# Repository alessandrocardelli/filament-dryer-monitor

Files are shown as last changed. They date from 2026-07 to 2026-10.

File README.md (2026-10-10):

# Filament Dryer Monitor

Custom ESP32-based controller board that retrofits an **eSUN eBox** filament dryer with closed-loop humidity/temperature control, a local OLED interface, data logging and a web UI.

The PCB physically replaces the original front panel: display and buttons sit on the front face of the board, while the main electronics are on the back.

> **Current status — 2026-10-08:** active hardware branch **main**. The released fabrication-source checkpoint remains **`74a3000127371ac6c3b3b7197f9036dec5b58eef`** (2026-09-17). First-article bring-up has validated MCU/USB/UART after the documented D020 collector-cross bodge, the four front-panel buttons, internal diagnostic LED, passive buzzer, SHT45, SSD1309 graphical output, fan driver/real fan and unloaded heater-switching path. The real heater remains blocked pending the real NTC/J7 path, final NTC conversion/fault handling and independent series TCO. The V1 front-panel interaction model is specified in `docs/UI_SPEC.md` and D022. A **SAFE BRING-UP** application now exists under `firmware/`: Slewform animated root-growth startup followed by a separate wordmark/chime (reproducible SVG-to-XBM export), OLED pages, SHT45 acquisition, button handling, persisted settings, modular cycle/fan/safety controllers and D021 LED patterns are implemented. The heater remains hard-locked LOW; the already-validated fan is now enabled only during DRYING test cycles with a provisional 100%/1 s kick-start followed by 40% at 25 kHz. See `docs/PROJECT_STATE.md` and `hardware/docs/PROCUREMENT.md`.

For a new work session, read AGENTS.md, docs/PROJECT_STATE.md, docs/DECISIONS.md and docs/TODO.md before changing the design.

---

## Features

- **SHT45** humidity/temperature sensor (I²C)
- **Characterized NTC thermistor** integrated into the heating element
- **1.54 in SSD1309 OLED** (128×64, I²C) + four front-panel buttons
- PWM heater control with hardware and firmware safety layers
- PWM fan control
- CSV logging to internal flash planned
- Web UI planned
- Powered from the dryer's 24 V supply; USB is used for programming/debug

## Safety concept

The project keeps three independent safety layers for the heater:

1. **Hardware TCO** in series with HEATER+, off-board and independent of the MCU.
2. **Firmware safety loop** using the heater NTC; an invalid/open sensor is treated as a fault and disables the heater.
3. **Compile-time gate**: heater drive is disabled until NTC calibration is explicitly enabled.

This is a personal project and not a certified product.

---

## Hardware

The board is a 4-layer KiCad 10 design intended for JLCPCB **bare-board fabrication and manual component assembly**. TME is the preferred prototype component supplier. The current KiCad schematic and PCB on the active branch are the authoritative implementation.

### Main blocks

| Block | Part | Notes |
|---|---|---|
| MCU | ESP32-WROOM-32E | Wi-Fi; final antenna copper/edge review remains a release item |
| Buck converter | **L7987L** | 24V_PROT -> 3.3 V, about 516 kHz, 1 A design target |
| Buck fault recovery | TLV1701AIDBVR + MMBT3904 | External AutoEN based on COMP fault detection |
| USB-UART | CP2102-GM | USB Full-Speed programming/debug |
| USB ESD | AKS1201 / USBLC6-2SC6-compatible topology | Two protected data channels |
| Humidity/temp | SHT45 | I²C 0x44 |
| Display | SSD1309 OLED 128×64 | I²C 0x3C |
| Heater driver | IRLR3636TRPBF | 60 V DPAK N-MOSFET, about 1.6 A heater load |
| Fan driver | IRLML2060TRPBF | 24 V fan low-side switch |
| Heater temperature | Integrated ~82 kΩ NTC | GPIO34 / ADC1, R28 = 47 kΩ, C19 = 100 nF |
| Buzzer | Passive buzzer + NPN | Defined startup state with base-emitter pull-down |

Heater and fan stay on 24V_PROT; they are not powered by the 3.3 V buck.

### L7987L electrical state

The active implementation is in hardware/Power.kicad_sch.

Key implemented parts/values:

| Ref | Value / part | Role |
|---|---|---|
| U5 | L7987L | Buck regulator |
| U1 | TLV1701AIDBVR | AutoEN comparator |
| Q7 | MMBT3904 | AutoEN EN pull-down |
| L1 | SRN6045-150M, 15 µH | Inductor |
| D7 | PMEG6030EP,115 | Catch diode, 60 V / 3 A Schottky |
| C1 | 10 µF / 100 V X7S | Main local input ceramic |
| C3 | 1 µF / 100 V X7S | Current local VIN/VCC bypass present in source |
| C6 | 100 nF | BOOT-LX bootstrap |
| C10 | 47 µF / 10 V X7R | Main pre-bead output capacitor |
| C21 | 1 µF / 25 V | VBIAS bypass |
| R4 | 47 kΩ | FSW, ~516 kHz |
| R29 | 47.5 kΩ | ILIM, ~1.705 A nominal |
| R36 / R34 | 49.9 kΩ / 16 kΩ | Feedback, ~3.295 V nominal |

Compensation: R33 = 16 kΩ, C9 = 18 nF, C8 = 39 pF, R35 = 1.13 kΩ, C20 = 560 pF.

Output architecture remains 3V3_BUCK -> FB1 -> 3V3_MCU. PGOOD and SYNCH are intentionally NC. The upstream C5 = 100 µF / 50 V bulk capacitor remains.

**VIN/VCC ceramic bypass — resolved:** ST requires a ceramic of 1 µF or higher across VIN-to-power-GND and another across VCC-to-IC-GND, close to the device. In the current design C1 = 10 µF / 100 V X7S already satisfies the VIN-side requirement, while C3 = 1 µF / 100 V X7S is the VCC bypass. The extra buck C22 added on 2026-09-09 was therefore redundant and was deliberately removed in commit `24a9170a`. Current C22 is unrelated: it is the CP2102 REGIN 1 µF / 25 V capacitor.

Detailed calculations and AutoEN rationale are in [docs/BUCK_L7987L_DESIGN.md](docs/BUCK_L7987L_DESIGN.md).

### Engineering review

The L7987L + AutoEN engineering review completed on **2026-09-04**. The accepted design basis remains:

- R29 = 47.5 kΩ -> ~1.705 A nominal current limit;
- conservative component-selection envelope ~1.42–2.15 A;
- actual sourced C1/C10 reviewed with class-II MLCC bias sensitivity;
- AutoEN reviewed COMP trip window ~1.56–2.07 V;
- recorded simulation ~59.1 kHz crossover, 64.9° phase margin, 19.6 dB gain margin.

These are engineering/simulation results; physical validation remains required.

The current `hardware/ERC.rpt` (2026-09-17) reports **0 errors and 0 warnings**. The existing GitHub ERC workflow contains the reviewed waiver logic, but its automatic push trigger currently names redesign/buck-sourcing, not the active pcb/l7987l-layout branch.

### Current PCB integration

The current board at hardware checkpoint `74a3000` contains the L7987L stage and AutoEN block on **B.Cu**. The old AP66200 stage and /Power/VCC_AP66200 are absent.

The saved 2026-09-17 DRC reports **0 active errors, 0 active warnings, 0 unconnected pads** and one **excluded** U4 B.Silkscreen-to-board-edge warning.

Local external copper/zones are present for 24V_PROT, /Power/3V3_BUCK, 3V3_MCU, HEATER_SW, LX and GND. Both internal layers remain solid GND.

The fabrication package has progressed to JLCPCB CAM review; this does **not** constitute physical validation of the assembled hardware.

### U5 exposed pad — resolved for planned hand assembly

U5 pad 17 is a 3.2 × 3.2 mm GND exposed pad on B.Cu. The accepted design intentionally uses **no via-in-pad**. Instead, six GND vias, each **0.60 mm diameter / 0.30 mm drill**, sit immediately outside the EP in two rows of three: 3 above and 3 below U5. This arrangement was implemented in commit `c9dc4129` and is present in the current PCB.

The peripheral vias provide a short thermal/GND path into the internal GND planes without placing open vias directly under the solderable exposed pad. For the planned prototype assembly, U5 is fitted by lightly pre-tinning the EP, applying flux and heating with hot air. Because this flow does not use a stencil for U5, the full B.Paste definition on pad 17 is not a prototype release blocker.

If the process later changes to stencil/reflow or external PCBA, paste-windowing and via treatment must be reopened for that process. First-board U5 temperature measurement remains part of validation. See decision D019 and `docs/ASSEMBLY.md`.

### CP2102-GM / USB

The classic CP2102-GM custom QFN footprint currently uses:

- 0.50 mm pitch;
- perimeter pads **0.95 × 0.28 mm**;
- exposed pad **3.25 × 3.25 mm**;
- solder-mask expansion **+0.06 mm**;
- **3 × 3** exposed-pad paste apertures, each 0.9 × 0.9 mm.

REGIN is on 3V3_MCU and now has a local **C22 = 1 µF / 25 V X7R 0603, Murata GCM188R71E105KA64J**, in addition to the local 100 nF decoupling.

USB differential routing:

- target: **90 Ω differential**;
- B.Cu referenced to In2.Cu;
- width: **0.20 mm**;
- gap: **0.25 mm**;
- KiCad tuning profile: **USB_90R**;
- long U2 -> U3 pair stays entirely on B.Cu with no vias;
- J2 A6/B6 = D+, A7/B7 = D−;
- U3 channel 1↔6 carries D+, channel 3↔4 carries D−;
- the short Type-C duplicated D+ fanout uses two signal vias and a short F.Cu bridge, with a nearby GND stitching via; D− stays on B.Cu.

The stored netlist was regenerated on 2026-09-17 after the MCU correction; USB pinout still requires first-board functional verification.

### Ground planes and stackup

| Layer | Role |
|---|---|
| F.Cu | Front components and signals |
| In1.Cu | **Solid GND plane** |
| In2.Cu | **Solid GND plane** |
| B.Cu | Back components/signals + local power copper |

Stackup entered in KiCad: 35 µm copper; 0.10 mm FR4 between F.Cu-In1 and In2-B.Cu; 1.24 mm FR4 core between inner layers; total board thickness 1.6 mm.

**Both inner layers are deliberately full GND.** There are no internal 3V3 or 24 V power planes.

For the L7987L, PGND and SGND are not separate project nets or split inner planes. They are current-return regions on the same GND net; local B.Cu geometry and via placement keep pulsed returns out of quiet control returns.

### Power distribution

Power remains on the external layers.

- 24V_PROT: wide traces/local zones are appropriate where current requires them.
- 3V3_BUCK: compact local copper around the buck output/Cout/FB1 path is preferred.
- 3V3_MCU: may remain mainly track-distributed, with local copper where useful.
- LX and other fast switched nodes: keep copper only as large as needed.

The capacitance from external power copper to the nearby GND plane is not a reason to avoid local power pours; the important restriction is minimizing fast switch-node area.

### Netclasses

| Class | Clearance | Track | DP width / gap | Via dia/drill |
|---|---:|---:|---:|---:|
| Default | 0.20 mm | 0.25 mm | 0.20 / 0.25 mm default | 0.60/0.30 mm |
| Power_3V3 | 0.20 mm | 0.50 mm | — | 0.60/0.30 mm |
| Power_24V | 0.20 mm | 1.00 mm | — | 0.80/0.40 mm |
| Power_Heat | 0.30 mm | 1.50 mm | — | 0.80/0.40 mm |
| USB | 0.20 mm | **0.20 mm** | **0.20 / 0.25 mm** | 0.60/0.30 mm |

USB data nets are USB_D+, USB_D−, USB_CONN_D+, USB_CONN_D−.

### Procurement

The working purchasing BOM is the Google Sheet **Filament Dryer Monitor — BOM finale Mouser**, tab **BOM TME**.

The live **BOM TME** was checked against the current production BOM/netlist: **94 mounted component references**, of which **61 items / 43 TME purchase rows** and **33 references marked in-house** for one assembled board. TME order was placed 2026-09-20. **C11 (22 µF, 25 V, X5R, 0805)** is outstanding: TME confirmed a stock-location problem and is checking its warehouse. No replacement/cancellation has been approved. The display, external sensor, heater thermal cutoff and mating cabling are outside this PCB purchasing BOM; their actual inventory remains to be checked.

See [hardware/docs/PROCUREMENT.md](hardware/docs/PROCUREMENT.md).

### Heater NTC characterization

The original eSUN heater includes an NTC whose exact manufacturer/part number is unknown. It was characterized in situ during cooldown after disconnecting it from the original controller.

| Temperature | Resistance |
|---:|---:|
| 25 °C | 82.5 kΩ |
| 28 °C | 75.5 kΩ |
| 30 °C | 67.4 kΩ |
| 35 °C | 51.7 kΩ |
| 40 °C | 43.6 kΩ |
| 44 °C | 35.93 kΩ |
| 50 °C | 28.8 kΩ |

The measurements are consistent with about 82 kΩ at 25 °C and a single-beta approximation near β ≈ 4100 K over the measured range. These are empirical measurements, not manufacturer specifications.

PCB interface: R28 = 47 kΩ 1%, C19 = 100 nF, GPIO34 / ADC1.

### GPIO map

| Function | GPIO |
|---|---|
| SDA / SCL | IO21 / IO22 |
| UART TX0 / RX0 | IO1 / IO3 |
| BOOT / RESET | IO0 / EN |
| Status LED | IO26 |
| Fan PWM | IO16 |
| Buzzer | IO33 |
| Heater PWM | IO19 |
| NTC | IO34 / ADC1 |
| Button ON/OFF | IO35 |
| Button M | IO32 |
| Button UP | IO14 |
| Button DOWN | IO27 |

Do not run a project-wide annotation reset when changing a hardware block; preserve established references or annotate only selected new circuitry.

---

## Firmware

Firmware uses the ESP32 Arduino core 3.x and is intended to remain cooperative/non-blocking in normal operation.

| Block | Status |
|---|---|
| SHT45 driver | Application driver implemented with non-blocking conversion wait and CRC validation |
| Fan PWM | Real DRYING-test control implemented: 25 kHz, 100%/1 s kick-start then provisional 40%; final FAN AUTO/cooldown still open |
| Heater + NTC safety | NTC characterized; conversion/calibration/safety implementation pending |
| OLED | First-article graphical output validated; SAFE BRING-UP renderer implemented |
| Buttons + UI state machine | Live-tested; SETUP and SETTINGS flows implemented, including persisted cycle/buzzer preferences |
| LittleFS + CSV logging | Pending |
| Web UI | Pending |
| Buzzer / LED | OFF/LOW/MED/HIGH volume, optional key click, startup/start/complete/warning/fault patterns and D021 LED semantics implemented; final acoustic tuning still pending |
| Non-blocking SHT45 conversion | Implemented in SAFE BRING-UP scaffold |

---

## Repository handoff files

~~~text
AGENTS.md                       Mandatory workflow before project work
docs/PROJECT_STATE.md           Current authoritative checkpoint
docs/DECISIONS.md               Durable engineering decisions
docs/TODO.md                    Immediate work list
docs/BUCK_L7987L_DESIGN.md      Detailed L7987L design/layout record
docs/ASSEMBLY.md                Assembly/bring-up sequencing
docs/UI_SPEC.md                 Front-panel V1 interaction specification
firmware/README.md               SAFE BRING-UP firmware status and usage
hardware/docs/PROCUREMENT.md    Sourcing/footprint/manufacturing state
hardware/*.kicad_*              Actual KiCad implementation
~~~

## Current next steps

1. Await TME's definitive response about **C11** and confirmation that the remaining available parts will ship; do not change the KiCad MPN or procurement BOM until an actual replacement/cancellation is agreed.
2. Verify the physical delivery, identities, quantities and packages of the TME order against the live `BOM TME` / `TME_IMPORT`; verify the stock of all items marked `In casa`.
3. Check availability and mechanical/electrical fit of off-board items (SSD1309 OLED, SHT45 sensor, independent heater thermal cutoff, mating connectors/cables and mounting hardware).
4. On receipt of the bare PCBs, inspect fabrication/assembly details and follow `docs/ASSEMBLY.md`; **leave R5 unfitted for initial 3.3 V bring-up**.
5. Perform first-board buck, USB, thermal and fault-recovery testing before normal heater operation. See `docs/PROJECT_STATE.md` and `docs/TODO.md`.

**First-article bring-up update (2026-10-04):** Gate 3 MCU/USB/UART is validated. CP2102 enumeration, bidirectional UART, ESP32 flashing, runtime serial output and automatic programming all pass on the prototype after the documented Q2/Q3 collector-cross bodge (D020). Next staged bring-up is Gate 4A I2C support.

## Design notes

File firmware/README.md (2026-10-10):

# Filament Dryer Monitor firmware

Current application phase: **SAFE BRING-UP with real fan control**.

## Implemented

- Slewform root-growth boot animation followed by a separate solo wordmark synchronized with the existing rising startup chime;
- SHT45 non-blocking acquisition with CRC validation;
- debounced ON/OFF, M, UP and DOWN handling, including long press/autorepeat;
- BOOT, STANDBY, SETUP, SETTINGS, DRYING-test, COMPLETE and FAULT presentation;
- `CycleController` for countdown/completion;
- `FanController` for the real first-article fan;
- `SafetyController` that continuously forces the heater output OFF;
- Preferences/NVS persistence for last cycle UI values, buzzer volume and key-click preference;
- buzzer OFF/LOW/MED/HIGH, optional key click, startup/start/complete/warning/fault sequences;
- D021 diagnostic LED patterns;
- cooperative/non-blocking main loop.

## Fan bring-up policy

The current fan policy is intentionally provisional:

- 25 kHz PWM;
- 100% duty for 1 s when a DRYING test cycle starts;
- 40% duty after kick-start;
- 0% on stop, completion or fault.

This retains margin over the measured first-article thresholds (25% first tested start duty, 15% lowest tested sustained duty). It is **not** the final FAN AUTO algorithm. Post-cycle cooldown remains undecided.

## Heater safety status

This is still **not heater-control firmware**.

GPIO19 / HEATER_PWM is configured as an output by `SafetyController` and forced LOW on every main-loop pass. There is no heater-enable path in this phase.

Do not add heater control until the real NTC/J7 path, NTC conversion/fault handling, independent TCO and heater safety gates are validated and recorded.

The target-temperature values visible in SETUP are UI prototype values only; they are not accepted heater limits.

## Persistence

ESP32 Preferences/NVS stores:

- last target-temperature UI value;
- last duration;
- buzzer volume;
- key-click preference.

The store avoids writes when values have not changed. Active/running-cycle state is not persisted and must not auto-resume after reset/power loss.

## Arduino environment

- ESP32 Arduino core 3.x
- U8g2 library
- Preferences library from the ESP32 Arduino core
- Board target: classic ESP32 / ESP32-WROOM-32E
- Serial monitor: 115200 baud

Open `firmware/firmware.ino` as the sketch.

## Slewform boot animation — reproducible export

Source of truth: `assets/slewform/Slewform_logo.svg`, unchanged.
The active asset is `assets/slewform/slewform_animation_compact.h`, regenerated
with `assets/slewform/generate_animation_compact.py`. The old combined
`slewform_logo_128x64.h` and `generate_logo.py` remain as legacy references.

The OLED boot sequence still lasts **3.5 s**:

- **0–1.5 s:** 11 levels of root growth (150 ms each); upper emblem fixed.
- **1.5–2.1 s:** full emblem held; **silent**.
- **2.1–3.5 s:** separate solo SLEWFORM wordmark; start rising chime on entry.
- **3.5 s:** STANDBY. The heater stays hard-locked OFF.

The 1-bit XBM/PROGMEM bitmap masks are: upper symbol 54×60 (420 bytes),
root geometry 54×60 (420 bytes), and wordmark 122×18 (288 bytes).
**Total bitmap data: 1,128 bytes** plus eleven 16-bit growth radii.
The renderer reveals root pixels by radius, non-blockingly, rather than
storing complete animation frames. `Ui::requestRender` forces the wordmark
refresh during the same main-loop pass as the chime's first note.

Regenerate from the repository root:

```sh
python -m pip install cairosvg pillow numpy
python firmware/assets/slewform/generate_animation_compact.py
```

The generator verifies XBM packing. Visual and chime timing must still be
validated on the physical OLED and buzzer after flashing the firmware.

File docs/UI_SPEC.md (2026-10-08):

# Front-panel UI specification

Status: **V1 interaction model accepted 2026-10-08**.  
Applies to the current first-article hardware on branch `main`.  
A first SAFE BRING-UP implementation now exists; actuator control and final safety integration remain pending.

This document defines the intended user interaction for the 1.54-inch SSD1309 128×64 OLED, the four front-panel buttons, the passive buzzer and the internal diagnostic LED. It does not define final heater-control gains, safety thresholds, temperature/time ranges or material-profile values; those remain gated by thermal/NTC validation.

## 1. Design goals

1. The dryer must be fully usable from the front panel without Wi-Fi, a phone or the web UI.
2. The normal workflow must remain simple enough to operate without nested menus.
3. Safety logic must remain independent of display/menu state.
4. Faults override normal UI presentation and cannot be cleared merely by silencing the buzzer.
5. The web UI is an additional interface for logging, history, diagnostics and advanced configuration; it is not required for ordinary drying cycles.
6. The front panel should expose the most useful live measurements at a glance: chamber temperature and relative humidity.

## 2. Hardware mapping

Current released hardware mapping:

| Front-panel function | Reference / signal | ESP32 GPIO |
|---|---|---:|
| ON/OFF button | SW3 / BTN_ONOFF | IO35 |
| M button | SW4 / BTN_M | IO32 |
| UP button | SW5 / BTN_UP | IO14 |
| DOWN button | SW6 / BTN_DOWN | IO27 |
| OLED | J4 / SSD1309, I²C address 0x3C | SDA IO21 / SCL IO22 |
| SHT45 | J3, I²C address 0x44 | SDA IO21 / SCL IO22 |
| Passive buzzer | BZ1 / BUZ_DRV | IO33 |
| Internal diagnostic LED | D3 / LED_DRV | IO26 |

All four front-panel buttons are active-low and have pull-ups. Short press, long press and UP/DOWN autorepeat are therefore firmware behaviors rather than hardware constraints.

Physical layout places ON/OFF and M on the left side of the display and UP/DOWN on the right.

## 3. Meaning of ON/OFF

ON/OFF is a **cycle-control button**, not a hardware power switch.

When the dryer has 24 V input power, the controller remains powered. In V1:

- after boot or reset, the controller enters safe `STANDBY`;
- heater and fan default OFF until application logic explicitly enables them;
- a drying cycle is never automatically resumed after power loss, reset or watchdog restart;
- restarting a previous cycle may be considered only as a future deliberate feature with appropriate safety handling.

## 4. Application state model

The V1 user-facing state machine is:

```text
BOOT
  |
  v
STANDBY <---- COMPLETE
  |
  v
SETUP
  |
  v
DRYING
  |
  +------> COMPLETE

BOOT / STANDBY / SETUP / DRYING / COMPLETE
                    |
                    +------> FAULT
```

`FAULT` has display and buzzer priority over all normal states. A future `COOLDOWN` state may be inserted between `DRYING` and `COMPLETE` if final fan-control policy requires it.

The UI state machine must not own heater safety. Control/safety logic independently decides whether heater and fan commands are permitted.

## 5. Button semantics

Default long-press threshold: approximately **1.5 s**, implemented as a firmware constant so it can be tuned after use testing.

### STANDBY

| Button | Short press | Long press |
|---|---|---|
| ON/OFF | Start the currently configured cycle | Same as short press or no extra action |
| M | Enter setup | Enter settings menu |
| UP | No direct action | No direct action |
| DOWN | No direct action | No direct action |

If the OLED is asleep, the first key press wakes the display and is consumed; it must not also start or modify a cycle.

### SETTINGS

From STANDBY, a long press on M opens SETTINGS. Initial persisted options:

- buzzer volume: OFF / LOW / MED / HIGH;
- key click: ON / OFF.

M short selects the next setting; UP/DOWN modify it; M long saves and returns to STANDBY. Settings are stored in ESP32 Preferences/NVS. Active-cycle state is never persisted for automatic restart.

### SETUP

V1 editable fields:

1. target chamber temperature;
2. cycle duration;
3. fan mode, initially `AUTO`.

Material presets are intentionally deferred until their actual values and safety/control implications are agreed. A later `PROFILE` field may provide PLA/PETG/TPU/etc. plus `MANUAL`.

| Button | Short press | Long press |
|---|---|---|
| ON/OFF | Start cycle using displayed settings | No additional action |
| M | Select next editable field | Cancel/return to standby |
| UP | Increase selected value | Autorepeat increase |
| DOWN | Decrease selected value | Autorepeat decrease |

The selected value is visually highlighted/inverted.

### Contextual button hints

Because the four physical buttons flank the OLED (ON/OFF upper-left, M lower-left, UP upper-right, DOWN lower-right), V1 should show very small context-sensitive action labels at the corresponding screen edges when useful. Initial first-article trial:

- STANDBY: `START` / `SET` on the left;
- SETUP: `START` / `NEXT` on the left and `+` / `-` on the right;
- DRYING / SYSTEM: `STOP` / `PAGE` on the left;
- COMPLETE: `OK` at upper-left;
- FAULT: `MUTE` at lower-left.

The hints use a very small font and must remain secondary to measurements/status. If first-article readability is poor or the display feels crowded, remove or abbreviate them rather than shrinking primary data.

### DRYING

Cycle parameters are **locked in V1 once the cycle starts**. This avoids accidental setpoint/time changes during initial application development.

| Button | Short press | Long press |
|---|---|---|
| ON/OFF | No stop action | Stop cycle and return to standby after confirmation/hold completes |
| M | Cycle information pages | Entering setup/settings is not allowed |
| UP | Reserved / no action in V1 | Reserved |
| DOWN | Reserved / no action in V1 | Reserved |

A later firmware revision may permit controlled in-cycle edits, but that is not part of V1.

### COMPLETE

- Heater is OFF.
- Fan behavior after cycle completion is defined by the final control policy; if a cooldown is required, the display must show it explicitly.
- ON/OFF short press acknowledges completion and returns to `STANDBY`.
- M may cycle the final measurement/summary pages until completion is acknowledged.

### FAULT

- Fault presentation overrides the current page.
- Heater is inhibited according to the safety controller.
- M short press silences/acknowledges the audible alarm only.
- Silencing the buzzer does **not** clear the fault and does not re-enable the heater.
- ON/OFF long press may request fault reset only after the underlying fault condition has cleared and the safety logic permits reset.
- If the fault remains present, the system stays in `FAULT`.

## 6. OLED content

The display is 128×64 monochrome. Layouts below are functional wireframes, not final pixel-perfect artwork.

### 6.1 BOOT

On power-up/reset, show the selected **Slewform logo with wordmark** centered on the OLED. The current branding asset is `firmware/assets/slewform/slewform_logo_128x64.h` (90×60 px).

The splash is accompanied by a **short original two-step rising startup chime**, intentionally giving a classic handheld-console startup feel without reproducing the Game Boy sound note-for-note. After first-article use testing, the splash duration is **3.5 s**; 1.5 s was judged too brief to read the branding comfortably.

Safety-critical initialization and safe output defaults happen before/under the splash; the branding sequence must not delay putting heater/fan outputs into their safe state. OLED initialization should blank the display before the first visible frame to suppress random power-up RAM artifacts. Initialization should remain non-blocking where practical.

### 6.2 STANDBY home screen

Primary information is live chamber temperature and relative humidity:

```text
 FILAMENT DRYER

 22.4 C      63 %RH

 Ready
```

The exact typography may use larger digits and unit glyphs than shown in the ASCII mock-up.

After an inactivity timeout (initial target about 60 s), the OLED may blank/sleep to reduce unnecessary OLED aging. The first subsequent button press only wakes it.

### 6.3 SETUP screen

```text
 SET CYCLE

 TEMP       [55 C]
 TIME        04:00
 FAN         AUTO
```

M moves the highlight. UP/DOWN modify the highlighted field.

Final allowed ranges, increments and defaults are **TBD** and must be set only after heater/NTC/control validation.

### 6.4 DRYING main page

```text
 DRYING        02:37
 54.8 C      18.6 %RH

 SET 55 C     FAN 65%
 HEAT ON
```

Priorities:

1. current chamber temperature;
2. current relative humidity;
3. remaining time;
4. target temperature;
5. actuator/control status in compact form.

If space is tight, temperature/RH and remaining time take precedence over secondary status text.

### 6.5 Technical/system page

Accessible with M while drying or from standby:

```text
 SYSTEM
 Chamber    54.8 C
 Heater     72.3 C
 H 63%       F 65%
```

The heater NTC temperature is intentionally a secondary/service value rather than the largest number on the normal screen.

### 6.6 Diagnostics page

Example:

```text
 STATUS
 SHT45       OK
 NTC         OK
 LOG         ON
 WiFi        AP
```

Only show states the firmware can actually determine reliably. Do not invent an `OK` state for unvalidated functions.

### 6.7 COMPLETE

```text
    COMPLETE

    54.1 C
    17.8 %RH

 Cycle finished
```

Completion remains visible until acknowledged or until an agreed timeout is added later.

### 6.8 FAULT

Use plain-language fault identification as the primary message rather than only an error number.

Example:

```text
 !! FAULT !!

 HEATER NTC
 invalid / open

 HEATER OFF
 M = mute
```

Another example:

```text
 !! OVER TEMP !!

 Heater 92.4 C

 HEATER OFF
```

A compact error code may also be logged/displayed for service diagnostics, but it should not replace the readable description.

## 7. Relative humidity in V1

SHT45 RH is always useful for live monitoring, logging and judging drying trend.

For V1, **relative humidity is not by itself an automatic cycle-termination criterion**. Heating changes RH strongly through temperature, so a robust humidity-based completion algorithm must be designed and validated deliberately before it can stop a cycle.

V1 completion is therefore time/control based. Humidity-driven or trend-driven completion is a future feature.

## 8. Fan behavior exposed to the UI

V1 exposes the fan as `AUTO` to the normal user.

The already measured first-article 25 kHz fan thresholds are 25% as the first tested start-from-rest duty and 15% as the lowest tested sustained-running duty. The current SAFE BRING-UP policy deliberately retains margin: 100% for 1 s at cycle start, then 40% for the remainder of the DRYING test cycle. This is a validation policy, not the final FAN AUTO algorithm. The fan stops immediately on cycle stop/completion for now; post-cycle cooldown remains open.

Manual fan percentage can remain available only on a technical/service page if needed for development. It is not a normal V1 cycle-setting requirement.

## 9. Buzzer behavior

BZ1 is passive and can vary frequency and approximate loudness using PWM duty cycle. First-article tests confirmed a tone around 2.7 kHz and a three-note melody; 50% duty was subjectively too loud.

Recommended V1 event mapping:

| Event | Audible behavior |
|---|---|
| Power-up / reset | short original two-step rising Slewform startup chime |
| Button/key feedback | optional very short tick; user-configurable |
| Cycle start | one short confirmation beep |
| Cycle complete | three-note ascending melody, played once |
| Recoverable warning | two short beeps |
| Safety fault | distinctive repeating alarm until muted/acknowledged |
| Fault reset accepted | one short confirmation beep |

Software loudness setting: `OFF / LOW / MED / HIGH`, with final PWM duty values tuned empirically. These are approximate acoustic levels, not calibrated sound-pressure levels.

Normal running must not generate repetitive beeps.

## 10. Internal diagnostic LED D3

D3 is **not** a user-facing indicator because it is hidden inside the installed dryer. It follows D021 unchanged:

| Diagnostic state | D3 pattern |
|---|---|
| Early boot / initialization | solid ON until initialization completes |
| Normal application running | heartbeat: ~100 ms ON every 2 s |
| Recoverable peripheral/sensor warning | double pulse every 2 s |
| Safety/fault state inhibiting controlled outputs | 250 ms ON / 250 ms OFF repeating |
| Board unpowered / firmware halted before LED initialization / GPIO unavailable | OFF |

The LED is useful during development and service after opening the dryer. Safety behavior must never depend on D3.

## 11. Firmware architecture requirements

The application should separate at least these concerns:

- **input manager**: debounce, short/long press, autorepeat;
- **UI state/presentation**: page selection and rendering;
- **cycle controller**: timer and high-level drying state;
- **sensor layer**: SHT45 and NTC acquisition/conversion;
- **safety controller**: independent permission/inhibition for heater operation;
- **fan controller**;
- **buzzer/event manager**;
- **logging layer**;
- **web interface**.

No display page, menu operation or buzzer state may bypass the safety controller.

The normal main loop must remain cooperative/non-blocking. Button holds, melodies, screen timeouts and sensor conversions should be timestamp/state driven rather than implemented with long blocking delays.

## 12. Persistence

V1 should persist user configuration such as:

- last target temperature;
- last cycle duration;
- buzzer loudness;
- key-feedback preference;
- future Wi-Fi/UI preferences as required.

Do **not** persist an active-cycle state in a way that causes automatic heater restart after reboot.

## 13. Items intentionally still open

The following are not decided by this UI specification:

- allowed target-temperature range;
- temperature adjustment step;
- minimum/maximum cycle duration and adjustment step;
- final heater control algorithm and gains;
- NTC conversion/calibration and all safety thresholds;
- fan AUTO policy and post-cycle cooldown duration;
- material profile list and profile values;
- humidity/trend-based automatic completion;
- exact fonts, pixel coordinates and iconography;
- exact buzzer PWM duty values for LOW/MED/HIGH;
- web UI structure;
- CSV/log format.

These must be resolved from hardware/safety validation and later application requirements rather than guessed from the panel design.

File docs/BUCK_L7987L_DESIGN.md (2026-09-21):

# L7987L buck redesign — current design record

Status: **schematic design basis accepted; bare-PCB fabrication files submitted, first-board validation pending** (2026-09-21).

Repository: alessandrocardelli/filament-dryer-monitor  
Current hardware branch: **pcb/l7987l-layout**  
Fabrication-source checkpoint before documentation-only commits: **74a3000127371ac6c3b3b7197f9036dec5b58eef** (2026-09-17, `Production files`).  
Hardware Design Manual-based schematic review completed on **2026-09-04**.  
The saved 2026-09-17 PCB DRC reports 0 active errors, 0 active warnings, 0 unconnected pads and 1 deliberately excluded U4 silkscreen/board-edge warning. The 2026-09-17 ERC reports 0 errors / 0 warnings.

The actual KiCad schematic and PCB override this document if they disagree. The active electrical implementation is in hardware/Power.kicad_sch; the current board implementation is hardware/Filament_Dryer_Monitor.kicad_pcb.

> **Current prototype / fabrication state**
>
> The board contains the L7987L redesign, not legacy AP66200. U5 retains six 0.60/0.30 mm GND vias arranged 3+3 *outside* the exposed pad for hand assembly. The current netlist/ERC/DRC and suffixed production exports are dated 2026-09-17; bare-PCB Gerbers/drills were uploaded to JLCPCB and the CAM production file was reviewed. GitHub does not verify subsequent fabrication/shipping status. No JLC PCBA or stencil was ordered/planned. C11 procurement remains unresolved with TME; the electrical design has not been changed.

> **Design-review result**
>
> The L7987L + AutoEN electrical calculations accepted on 2026-09-04 remain the design basis: ILIM/L1 selection, capacitance/compensation sensitivity and AutoEN corners are not reopened by PCB routing alone. Physical ringing, thermal behavior, real load transients, fault current and AutoEN timing remain prototype validation items.

## 1. Design objective

Replace the previous AP66200 24 V -> 3.3 V buck with a sourceable high-voltage regulator while preserving the rest of the board architecture.

Selected regulator:

- STMicroelectronics **L7987L**;
- asynchronous buck;
- 4.5–61 V operating input range;
- 2 A capability;
- adjustable switching frequency;
- programmable peak current limit;
- external compensation.

Primary manufacturer source:

- STMicroelectronics, **L7987L — 61 V, 2 A asynchronous step-down switching regulator with adjustable current limitation**, DocID026362 Rev. 4;
- https://www.st.com/resource/en/datasheet/l7987l.pdf

AutoEN comparator:

- TI **TLV1701AIDBVR**;
- 2.2–36 V supply;
- rail-to-rail input common-mode;
- open-collector output;
- https://www.ti.com/lit/ds/symlink/tlv1701.pdf

ST layout reference:

- **STEVAL-ISA198V1**, L7987L demonstration/evaluation board;
- use the official ST layout and Gerbers as the primary topological/geometric reference, adapted to this board's four-layer stackup and actual footprints.

---

## 2. Electrical requirements

### Load topology

Heater and fan are not supplied by the 3.3 V buck.

- Heater: `24V_PROT`, low-side switched, approximately 1.6 A at 24 V.
- Fan: `24V_PROT`, low-side switched, approximately 0.2 A.
- Buck: low-voltage electronics only.
- Buck output -> `3V3_BUCK` -> FB1 -> `3V3_MCU`.

3.3 V load budget used during design:

- conservative normal load ~0.66 A;
- including SHT45 internal-heater case ~0.76 A;
- adopted buck design target **1.0 A**.

Input engineering range: **21.6–26.4 V** around 24 V nominal. This ±10% range is a project engineering assumption, not a verified tolerance specification of the original eSUN supply.

Original supply is 24 V / 48 W. The combined design-point load leaves limited source margin; a future 24 V / 3 A / 72 W minimum replacement remains a sensible target, but no replacement supply is selected in this record.

---

## 3. Implemented topology

### Input / VCC / bypass

24V_PROT directly supplies L7987L VIN1, VIN2 and VCC.

Current source implementation:

- C1 = 10 µF / 100 V X7S, main local input ceramic.
- C3 = 1 µF / 100 V X7S, local L7987L VCC/input bypass.
- C2 = 100 nF, local TLV1701 supply bypass.
- C5 = 100 µF / 50 V, upstream bulk reservoir retained.

**VIN/VCC local ceramic requirement — resolved:** ST requires a ceramic of 1 µF or higher across VIN-to-power-GND and another across VCC-to-IC-GND, close to the device. C1 = 10 µF / 100 V already satisfies the VIN-side requirement; C3 = 1 µF / 100 V is the VCC bypass. The additional 1 µF / 100 V buck C22 added on 2026-09-09 was redundant and was deliberately removed in commit `24a9170a`. D018 supersedes historical D012.

### Output / VBIAS

- C10 = 47 µF main pre-bead output capacitor.
- C21 = 1 µF / 25 V VBIAS/output bypass.
- pre-bead node = 3V3_BUCK.
- FB1 feeds 3V3_MCU.

### Unused pins

- U5 pin 12 PGOOD: intentionally NC.
- U5 pin 7 SYNCH: intentionally NC.

## 4. Current reference/value map

### Active devices / magnetics

| Ref | Current device | Role |
|---|---|---|
| U5 | L7987L | Buck regulator |
| U1 | TLV1701AIDBVR | AutoEN comparator |
| Q7 | MMBT3904 | AutoEN EN pull-down |
| L1 | SRN6045-150M, 15 µH | Buck inductor |
| D7 | PMEG6030EP,115 | Catch Schottky; Nexperia 60 V / 3 A CFP5/SOD-128 |

### Buck and AutoEN capacitors

| Ref | Value | Role |
|---|---:|---|
| C1 | 10 µF / 100 V X7S | Main local input ceramic |
| C2 | 100 nF | TLV1701 bypass |
| C3 | 1 µF / 100 V | L7987L VIN/VCC local bypass |
| C4 | 33 nF | Soft start |
| C6 | 100 nF | BOOT-to-LX bootstrap |
| C7 | 330 nF | AutoEN EN timing |
| C8 | 39 pF | Type-III CP |
| C9 | 18 nF | Type-III CF |
| C10 | 47 µF / 10 V X7R | Main buck output capacitor |
| C20 | 560 pF | Type-III CS |
| C21 | 1 µF / 25 V | VBIAS/output bypass |

### Buck and AutoEN resistors

| Ref | Value | Role |
|---|---:|---|
| R1 | 270 kΩ | AutoEN threshold top |
| R2 | 22 kΩ | AutoEN threshold bottom |
| R4 | 47 kΩ | FSW programming |
| R5 | 100 kΩ | TLV1701 open-collector pull-up |
| R6 | 100 kΩ | Comparator output to Q7 base |
| R29 | 47.5 kΩ | ILIM programming |
| R30 | 47 kΩ | Q7 base-emitter pull-down |
| R31 | 100 kΩ | EN pull-up |
| R32 | 15 kΩ | EN pull-down |
| R33 | 16 kΩ | Type-III RF |
| R34 | 16 kΩ | Feedback lower resistor |
| R35 | 1.13 kΩ | Type-III RS |
| R36 | 49.9 kΩ | Feedback upper resistor |

---

## 5. Switching frequency

ST relation:

`FSW [kHz] = 250 + 12500 / RFSW [kΩ]`

With R4 = 47 kΩ:

`FSW ≈ 516 kHz`

The layout is therefore treated as a practical ~500 kHz switcher.

---

## 6. Feedback divider

- R36 upper = 49.9 kΩ.
- R34 lower = 16 kΩ.
- nominal L7987L VFB = 0.800 V.

`VOUT = VFB × (1 + R36/R34) ≈ 3.295 V`

Using ST's feedback-reference limits 0.788–0.812 V gives approximately 3.246–3.344 V before resistor-tolerance/bias terms.

---

## 7. Inductor, ripple and catch diode

L1 = Bourns SRN6045-150M:

- 15 µH nominal;
- ±20% tolerance;
- DCR max ~95.8 mΩ;
- Irms ~1.9 A;
- Isat ~2.3 A, defined by Bourns at 30% inductance reduction.

At ~516 kHz over the 21.6–26.4 V design range:

- nominal inductor ripple ~0.36–0.37 A p-p;
- normal peak at 1.0 A load ~1.18–1.19 A;
- with L at -20%, normal high-line peak ~1.23 A.

The actual released D7 is **Nexperia PMEG6030EP,115, 60 V / 3 A Schottky**, CFP5/SOD-128 (KiCad MPN `PMEG6030EP.115`). Earlier STPS2L60A references in design notes are historical and **not the populated source**. First-board probing must still verify LX ringing, D7 temperature and switching stress; the rating does not by itself establish measured margin.

---

## 8. Current-limit programming — CLOSED

R29 = 47.5 kΩ.

ST relation:

`RILIM = 27 kΩ × 3 A / ILIM`

Nominal project value:

`ILIM,nom ≈ 1.705 A`

ST does not publish a guaranteed min/max specifically at 47.5 kΩ. For component-selection review, a deliberately conservative engineering envelope based on the published ST current-limit spread plus R29 tolerance was used:

- lower estimate ~1.42 A;
- upper stress estimate ~2.15 A.

The lower estimate remains above the normal worst-case operating peak (~1.23 A). The upper estimate remains below L1's ~2.3 A Isat. The 2.15 A number is an engineering stress estimate, not a manufacturer-guaranteed maximum at 47.5 kΩ.

**Gate: CLOSED for schematic sign-off.** Prototype fault-current/current-waveform measurement remains required.

---

## 9. Input/output capacitance — CLOSED FOR SCHEMATIC SELECTION

Sourced power capacitors:

- C1 = Murata `GRM32EC72A106KE05L`, 10 µF / 100 V / X7S / 1210.
- C10 = Taiyo Yuden `LMK325B7476KM-PR`, current number `MSASL32MSB7476KPNB25`, 47 µF ±10% / 10 V / X7R / 1210.
- C3 = 1 µF / 100 V local bypass.
- C21 = 1 µF / 25 V VBIAS bypass.
- C5 = 100 µF / 50 V upstream bulk.

Manufacturer data confirms nominal ratings and provides bias/temperature characterization or simulation data. Those curves/models are not treated as a guaranteed minimum capacitance specification. The schematic review therefore used conservative reduced-capacitance stress cases rather than inventing `Ceff,min`.

A severe 23.5 µF C10 stress case was checked during review; it did not invalidate the selected compensation architecture or the recorded crossover relative to the ~500 kHz switching frequency.

**Gate: CLOSED for schematic selection.** Physical load-transient behavior remains a bring-up measurement.

---

## 10. Type-III compensation

Final network:

- R33 / RF = 16 kΩ;
- C9 / CF = 18 nF;
- C8 / CP = 39 pF;
- R35 / RS = 1.13 kΩ;
- C20 / CS = 560 pF.

Recorded final-value simulation results:

- crossover ~59.1 kHz;
- phase margin ~64.9°;
- gain margin ~19.6 dB.

Recorded transient run (~0.33 A -> 1.32 A):

- VOUT,min ~3.254 V;
- VOUT,max ~3.361 V;
- inductor-current peak ~1.59 A;
- clean recovery.

These are session-recorded SIMPLIS/eDSim results, not measurements from physical hardware.

---

## 11. AutoEN rationale and implementation — CLOSED

Deep-short simulation of the L7987L model showed COMP could remain strongly saturated during a persistent fault. Resetting EN cleared the loop state and produced a clean restart. The final design therefore adds an external AutoEN detector that forces EN low when COMP rises above a chosen threshold.

U1 = TLV1701AIDBVR:

- IN+ -> L7987L COMP;
- IN− -> `VREF_FAULT`;
- V+ -> `24V_PROT`;
- V− -> GND;
- C2 = 100 nF local bypass;
- open-collector OUT uses R5 pull-up and R6/Q7 drive.

Threshold divider:

- R1 = 270 kΩ from `24V_PROT` to `VREF_FAULT`;
- R2 = 22 kΩ from `VREF_FAULT` to GND.

Nominal threshold:

- 21.6 V input -> ~1.627 V;
- 24.0 V -> ~1.808 V;
- 26.4 V -> ~1.989 V.

Corner review included input range, ±1% divider tolerance, conservative 100 ppm/K opposing TCR and TLV1701 input-error terms. Reviewed COMP trip window is approximately **1.56–2.07 V**.

EN network:

- R31 = 100 kΩ from 24V_PROT to EN;
- R32 = 15 kΩ EN to GND;
- C7 = 330 nF EN to GND;
- Q7 collector pulls EN low during fault.

Nominal VEN ~3.13 V at 24 V; reviewed low-line/tolerance EN-high remains ~2.7 V or higher, comfortably above the L7987L maximum enable-high threshold of 0.9 V.

Recorded persistent-fault simulation showed repeated shutdown/retry and clean eventual restart after the fault was removed.

### 11.1 Why AutoEN is required — foldback lock, identified 2026-09-09

The original justification recorded here was only "COMP remained saturated in a deep-short
simulation". The actual mechanism has since been isolated and is more specific than that.

Overload/recovery simulation, SIMPLIS, testbench derived from
`TB_L7987L_STEVAL-ISA198V1_LoadTransient` with project values
(24 V in, 3.3 V out, L1 15 µH / 95.8 mΩ, RILIM 47.5 kΩ, RFSW 47 kΩ,
COUT 23.5 µF and CIN 7.5 µF as DC-bias-derated effective values).
Load stepped 1 A -> 3 A at 20 ms, released at 45 ms, run to 60 ms.

Observed sequence:

1. During the fault FB falls below the 400 mV `VFOLD` threshold and the peak current limit
   folds back to one third. Inductor current drops from ~1.2 A to ~0.45 A, confirming that
   the model does implement the datasheet section 4.5 protections — the earlier suspicion
   that this was an incomplete-model artifact is disproved.
2. After the fault is removed the converter can only deliver the folded-back current.
3. ~0.45 A into the 3.3 Ω recovery load settles the output at ~1.5 V.
4. At 1.5 V the divider puts FB at ~0.36 V, still below the 400 mV threshold.
5. Foldback therefore never releases. The converter latches in a stable sub-threshold
   operating point and does not return to 3.3 V within the simulated window.

The margin is thin: leaving foldback needs roughly 1.65 V at the output and the circuit
settles at ~1.5 V, about 150 mV short. The datasheet statement that the full limit is
restored as soon as FB rises above `VFOLD` is correct but not sufficient — nothing in the
device drives FB back across the threshold.

The device protection prevents inductor current runaway. It does not guarantee recovery.
Those are separate properties and only the first is covered by the datasheet analysis.

### 11.2 Measured COMP levels and threshold placement

From the same simulation:

| Condition | COMP |
|---|---|
| Steady state, 1 A load | ~0.25 V |
| Persistent fault | ~3.3 V (saturated) |

The R1/R2 threshold window of approximately 1.56–2.07 V sits between the two with wide
margin on both sides. This supersedes the earlier tolerance-only corner analysis with
observed levels, and removes a previously raised concern that input-rail sag from heater
switching could drag the threshold into a false trip: at 0.25 V steady-state COMP the
available margin is roughly a factor of six.

### 11.3 Single-failure direction — R5 not populated at first assembly

U1 has an open-collector output. If U1 is absent, damaged, or has an unsoldered pin, the
output node is pulled up through R5, Q7 conducts and EN is held low. The board produces no
3.3 V rail at all.

This is the wrong failure direction for an auxiliary protection block: a fault-recovery
accessory should degrade to "unprotected but working", not to "dead board". The practical
exposure is assembly rather than field failure — U1 is a hand-soldered SOT-23-5, and a
single cold joint at first power-up presents as a dead buck, sending debugging effort to
U5, L1 and the feedback network while the regulator itself is healthy.

Resolution is assembly order, not a schematic change. R5 is left unpopulated for initial
bring-up; R30 then holds the Q7 base at ground, Q7 stays off and EN is free. See
`docs/ASSEMBLY.md`.

**Gate: CLOSED for schematic sign-off.** Comparator propagation, EN timing, COMP waveform and restart behavior remain prototype measurements.

---

## 12. ERC / schematic-regression state

The current saved `hardware/ERC.rpt` is dated **2026-09-17 22:18:03** and reports **0 errors / 0 warnings**. The regenerated `hardware/Filament_Dryer_Monitor.net` is dated 2026-09-17 21:13:01 and includes the corrected USB-C J2 D+/D− mapping. The older 2026-09-16 external-GND error and reversed netlist were pre-release checkpoints and are not current-source findings.

The current ERC report lists specific ignored check classes. The repository workflow/branch trigger should be checked before assuming an automatic ERC run on future feature-branch hardware changes. A documentation-only commit does not change the validated KiCad source or require a fresh hardware report.

**Gate:** schematic release evidence is recorded; electrical and thermal behavior remains to be verified on the assembled prototype.

## 13. Sourcing / footprint state

The current released purchasing BOM is the live Google Sheet `BOM TME`, reconciled against the **suffixed** `hardware/production/Filament_Dryer_Monitor_bom.csv` and the current schematic netlist. The legacy unsuffixed `hardware/production/bom.csv` still describes the previous AP66200/CP2102N build and must **not** be used for this design. The old suffixed export's `LCSC Part #` heading is not a reliable TME code; use `BOM TME` column `Codice TME`.

Important current package/footprint facts:
- C5 Panasonic EEEFK1H101P -> custom Panasonic size-F footprint.
- J2 GCT USB4216-03-A -> custom USB-C footprint.
- L1 SRN6045-150M -> custom Bourns footprint.
- U2 CP2102-GM -> custom QFN28 footprint with 0.95 × 0.28 mm perimeter pads, +0.06 mm mask expansion, 3.25 × 3.25 mm EP and 3 × 3 array of 0.9 mm paste apertures.
- SW1–SW6 GCT SWT0110-020010SSA -> custom footprint.
- BZ1 LD-BZEL-T67-0808 -> custom footprint with conservative terminal lands.
- U5 L7987L -> SamacSys_Parts:SOP65P640X120-17N HTSSOP-16 with exposed pad and six nearby peripheral ground/thermal vias; no via-in-pad for **U5**.

Current CP2102 REGIN bypass is C22 = GCM188R71E105KA64J, 1 µF / 25 V / X7R / 0603. VIN/VCC bypass choices are C1 10 µF / 100 V and C3 1 µF / 100 V; no C22 duplicate.

**Current supply-only exception, not a circuit change:** one-board TME order placed 2026-09-20. C11 = Samsung `CL21A226MAYNNNE`, 22 µF / 25 V / X5R / 0805 on `3V3_MCU` is **not confirmed available for dispatch**; TME is investigating an unlocatable warehouse item. A TDK 22 µF / 16 V / X5R / 0805 equivalent (`C2012X5R1C226M125AC`, TME `C2012X5R1C226MAC`) has been discussed **only as a possible substitution**. No product swap or cancellation is authorized. Keep C11 in the final hand assembly and wait for TME's answer; check usable capacitance at 3.3 V before changing the sourced MPN.

The U5 exposed-pad strategy remains closed for **manual** prototype assembly: lightly pre-tin the pad, use flux and hot air. If the assembly flow later switches to stencil/reflow or external PCBA, reopen solder-paste/via-treatment decisions explicitly.

The OLED, off-board SHT45, independent heater cutoff, cabling/mating JST parts and mechanical fasteners are not PCB-mounted BOM lines; check them separately. Full ordering details and open work: `hardware/docs/PROCUREMENT.md`.

## 14. PCB synchronization / routing checkpoint

Verified at released hardware checkpoint `74a3000`:

- current PCB contains U5 = L7987L on B.Cu;
- old AP66200 and /Power/VCC_AP66200 are absent;
- AutoEN is present on B.Cu;
- local B.Cu zones exist for 24V_PROT, /Power/3V3_BUCK, 3V3_MCU, GND, HEATER_SW and LX;
- both inner layers contain full-board GND zones;
- fresh DRC reports **0 unconnected pads**.

Therefore schematic-to-board integration and basic routing connectivity are no longer open tasks. The remaining gate is engineering/manufacturing review.

The stored netlist was regenerated on 2026-09-17 after the MCU correction and now maps J2 A6/B6 to D+ and A7/B7 to D−. Verify USB functionality on the assembled board; there is no current-source reversed-netlist blocker.

## 15. Current stackup and grounding decision

KiCad stackup:

- F.Cu 35 µm;
- 0.10 mm FR4, Er 4.5;
- In1.Cu 35 µm;
- 1.24 mm FR4 core, Er 4.5;
- In2.Cu 35 µm;
- 0.10 mm FR4, Er 4.5;
- B.Cu 35 µm;
- total 1.6 mm.

**Project decision:**

- In1.Cu = solid GND plane;
- In2.Cu = solid GND plane;
- no 3V3 or 24 V internal power planes;
- buck local power distribution uses B.Cu copper/tracks/zones.

For the B.Cu buck, In2 is the nearest GND reference only 0.10 mm away.

### PGND / SGND implementation

ST explicitly distinguishes power-ground and signal-ground current paths in the L7987L layout guidance. This project implements that intent **without separate GND nets and without splitting the internal planes**.

Same electrical `GND` net:

- high-current/pulsed return region: C1 negative, D7 anode, C10 negative;
- quiet/signal return region: U5 pin 16 + exposed pad, C3 negative, C21 negative and sensitive control returns.

Both use short local B.Cu connections/vias into the same continuous In1/In2 GND planes. The design goal is to prevent the pulsed input/catch-diode/output return current from flowing through the quiet local return geometry around FB/COMP.

Do not create a split In2 PGND/SGND plane as an interpretation of the ST diagram.

---

## 16. ST layout guidance applied to the current PCB

Verified ST guidance that controls the current layout:

- minimize the high-pulsed-current step-down loop;
- place a small ≥1 µF bypass as close as possible to the input-voltage pin for both VIN and VCC;
- keep FB divider close to the device and away from high-current paths;
- connect EP to signal GND while avoiding high current through signal-ground copper;
- use a short BOOT-to-LX capacitor connection;
- use the demonstration-board layout as the device-specific reference.

Reference-board component mapping used during placement:

| ST demo | Project |
|---|---|
| U1 | U5 |
| D1 | D7 |
| L1 | L1 |
| C1+C2 main input | C1 10 µF |
| local 1 µF input/VCC bypass | C3 1 µF |
| C5 output | C10 |
| C7 bootstrap | C6 |
| C10 soft start | C4 |
| R8 FSW | R4 |
| R9 ILIM | R29 |
| R6/C9/C11 | R33/C9/C8 compensation |
| R5/C8 | R35/C20 compensation |
| R7/R11 feedback | R36/R34 |

C21 has no direct demonstration-board equivalent in that mapping; it is the project VBIAS/output bypass.

### Placement facts to preserve

- In the current physical board view, VIN/VCC are on the **left side of U5**.
- C3 belongs closest to VIN/VCC.
- C1 belongs on the same VIN side and may be slightly farther out than C3.
- C21 stays close to pin 1 VBIAS; it does not need to be moved merely to make a continuous surface PGND strip between C1 and D7.
- C6 is BOOT-LX, not a GND return component.
- FB/COMP network stays in the quiet region.

### Bottom-side orientation process rule

Do not infer B.Cu pad direction from raw local footprint coordinates. A previous manual transform led to incorrect rotation recommendations. Use KiCad/pcbnew absolute pad positions or the actual board view with nets/pad numbers.

---

## 17. Current PCB open items

### U5 exposed pad / thermal implementation — CLOSED for planned hand assembly

U5 pad 17 is the 3.2 × 3.2 mm exposed GND / SGND pad centered with U5 at approximately `(174.649, 85.116)`.

The accepted implementation is deliberately **not via-in-pad**. Six GND vias are placed immediately outside the EP:

- 0.60 mm via diameter;
- 0.30 mm drill;
- three vias in a row above U5 at approximately y = 82.9 mm;
- three vias in a row below U5 at approximately y = 87.35 mm;
- x positions around 173.75 / 174.65 / 175.55 mm.

This arrangement was implemented in commit `c9dc4129` and remains present in the current PCB. It gives the exposed pad a short thermal/electrical path to the internal GND planes without placing open vias in the solderable EP, avoiding the via-in-pad solder-wicking problem that motivated the 3+3 peripheral arrangement.

For the planned prototype flow, U5 is assembled manually with a very light pre-tin on the exposed pad, flux and hot air. The footprint still contains full-area B.Paste on pad 17, but that layer is not used to meter solder in this hand-assembly process and is therefore not a prototype release blocker.

If the manufacturing method changes to stencil/reflow or external PCBA, reopen the paste-window and via-treatment decision for that process. First-board U5 temperature measurement remains a validation requirement. Decision D019 records the closure.

### VIN/VCC bypass status

Closed by D018. C1 provides the required local VIN ceramic capacitance (10 µF ≥ 1 µF) and C3 provides the required 1 µF VCC bypass. No additional dedicated buck C22 is required. Final layout review must still verify that C1/C3 and their respective GND return paths remain genuinely local.

### Buck routing review

All current nets are connected, but final quality review is still required for:

- C1/C3 -> VIN/VCC loop;
- C6 BOOT-LX;
- U5 LX -> D7/L1 switching region;
- L1 -> C10 -> 3V3_BUCK -> FB1;
- FB/COMP routing and quiet return;
- AutoEN routing;
- high-current versus quiet GND via entry.

No generic wide LX netclass is required; switch-node copper is controlled geometrically and kept compact.

## 18. Netclasses and USB geometry

Current classes:

| Class | Clearance | Track | Via dia/drill |
|---|---:|---:|---:|
| Default | 0.20 mm | 0.25 mm | 0.60/0.30 mm |
| Power_3V3 | 0.20 mm | 0.50 mm | 0.60/0.30 mm |
| Power_24V | 0.20 mm | 1.00 mm | 0.80/0.40 mm |
| Power_Heat | 0.30 mm | 1.50 mm | 0.80/0.40 mm |
| USB | 0.20 mm | **0.20 mm** | 0.60/0.30 mm |

USB geometry is now closed for the current stackup:

- B.Cu signal layer;
- In2.Cu reference;
- 0.10 mm FR4, Er 4.5;
- 90 Ω differential target;
- width 0.20 mm;
- gap 0.25 mm;
- profile USB_90R.

Assignments use USB_D+, USB_D−, USB_CONN_D+, USB_CONN_D−.

The long U2-to-U3 pair stays on B.Cu with no vias. The short Type-C D+ duplicate-pad crossover uses two local vias and a short F.Cu bridge with nearby GND stitching; D− remains on B.Cu.

## 19. DFT / debug access

Existing access includes `24V_PROT`, `3V3_MCU` and GND.

Before routing freeze, decide whether to add convenient test access for:

- `3V3_BUCK` before FB1;
- COMP;
- EN / AutoEN control node;
- local GND near the buck.

Avoid creating a large LX test pad. If LX probing is needed, use an existing switch-node pad with a very short probe ground arrangement.

---

## 20. DRC / manufacturing state

The saved `hardware/DRC.rpt` was generated on **2026-09-17 22:18:19** from the released routed PCB: **0 active errors / 0 active warnings / 0 unconnected pads / 0 footprint errors**, plus one **excluded** U4 B.Silkscreen-to-board-edge `silk_edge_clearance` item. The old 2026-09-16 list of 14 active warnings is obsolete.

Current suffixed production BOM/position files and final Gerbers/drills were generated for the release-source checkpoint `74a3000`. The final Gerbers/drills were uploaded to JLCPCB for **bare-PCB** production; a supplier CAM/production ZIP was received and compared with the uploaded Gerbers. This review does not by itself confirm subsequent approval, manufacturing or shipment, and does not replace incoming physical inspection or prototype validation.

No hardware change is made by this documentation update. Do not regenerate or overwrite the released fabrication outputs merely to reflect a later supplier replacement of one same-footprint component; record an actual assembly substitution explicitly and require fresh design outputs only if the hardware itself changes.

## 21. Next implementation sequence

1. Wait for the TME warehouse investigation of C11 and confirm dispatch of the other ordered components. Resolve any substitute/refund/reorder cost **before** changing the purchasing source.
2. Audit actual delivered parts and the 33 component references marked in-house; verify availability of off-board OLED, SHT45, thermal cutoff, cabling/mating connectors and mounting hardware.
3. Inspect the delivered bare board (JLCPCB status/stackup, mask, drill and component fit), especially U2 solderability and U4 antenna edge.
4. Hand assemble with **R5 initially unpopulated**; verify 3.3 V before installing R5 and enabling AutoEN.
5. Perform first-board USB, buck/load-transient, LX ringing, D7/U5/L1 thermal and current-limit/AutoEN tests. Complete independent heater TCO/NTC safety validation before normal heating.
6. Any changes resulting from real-board tests belong to a new documented revision, not a silent rewrite of the already submitted fabrication checkpoint.

**Current project gate:** the accepted L7987L + AutoEN electrical decisions and the 2026-09-17 hardware release remain the source of truth. The open tasks are **physical procurement, assembly and testing**; C11 is the one supplier-disclosed unlocated PCB-mounted part, not a resolved substitution.

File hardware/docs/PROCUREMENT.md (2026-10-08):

# Procurement and footprint state

Status: **2026-09-21 — bare-PCB fabrication package submitted; one-board TME order placed, C11 supply issue open; manual assembly pending** on branch **pcb/l7987l-layout**.

Fabrication-source checkpoint (before documentation-only commits): **74a3000127371ac6c3b3b7197f9036dec5b58eef** (2026-09-17, `Production files`).

## Source of truth

The current KiCad schematic and PCB on the active branch are authoritative for implementation. A freshly exported netlist is authoritative for schematic connectivity only when it has been regenerated after the latest schematic edit.

The purchasing source is the Google Sheet **Filament Dryer Monitor — BOM finale Mouser**, tab **BOM TME**, together with manufacturer/MPN fields synchronized into KiCad.

If documentation disagrees with the actual KiCad files, the KiCad implementation wins. If the live purchasing sheet disagrees with current KiCad references, reconcile it before ordering.

## Current PCB/manufacturing state

The 2026-09-17 KiCad release contains L7987L U5, AutoEN, IRLML2060TRPBF Q5, Nexperia PMEG6030EP.115 D7 and both continuous inner GND planes; legacy AP66200 is absent. Current `hardware/ERC.rpt`: **0 errors, 0 warnings** (2026-09-17 22:18). Current `hardware/DRC.rpt`: **0 active errors, 0 active warnings, 0 unconnected pads, 0 footprint errors**, with one **excluded** U4 B.Silkscreen/board-edge warning (2026-09-17 22:18). The 2026-09-17 netlist correctly maps USB-C A6/B6 to D+ and A7/B7 to D−.

The current PCB and drill/Gerber package was uploaded to JLCPCB as a **bare 4-layer PCB**, with **manual component assembly** planned (no JLC PCBA or stencil). JLCPCB's CAM/production ZIP was received and reviewed against the original uploaded Gerbers in the order conversation. GitHub does not independently establish whether the order has entered fabrication or shipped; inspect the actual manufacturer order status.

**Correct current release exports:** `hardware/production/Filament_Dryer_Monitor_bom.csv` and `Filament_Dryer_Monitor_positions.csv`. The similarly named **unsuffixed** `hardware/production/bom.csv`, `positions.csv` and `designators.csv` belong to an **obsolete AP66200 / CP2102N-era BOM** and are not an acceptable purchasing or assembly source for this revision. The current suffixed export retains an `LCSC Part #` column with heterogeneous legacy/supplier identifiers, **not necessarily valid LCSC order codes**. Use the live sheet's `Codice TME` field when procuring from TME.

## Current DRC warning set

The previously documented 2026-09-16 14-warning set was resolved in the saved 2026-09-17 DRC. Only the intentionally **excluded** U4 B.Silkscreen/board-edge `silk_edge_clearance` item remains in the report. This does not prove mechanical fit, RF behavior, or final solderability; check the first delivered PCB. A documentation-only commit does not require regenerating ERC/DRC; any new hardware revision does.

## Closed sourcing basis

The component-selection basis remains:

- U5 = L7987L;
- U1 = TLV1701AIDBVR;
- Q7 = MMBT3904;
- L1 = SRN6045-150M, 15 µH;
- D7 = Nexperia PMEG6030EP,115 / KiCad MPN PMEG6030EP.115, 60 V / 3 A Schottky, CFP5/SOD-128;
- R29 = 47.5 kΩ ILIM;
- R33 = 16 kΩ, R34 = 16 kΩ, R35 = 1.13 kΩ 0.1%, R36 = 49.9 kΩ;
- C1 = Murata GRM32EC72A106KE05L, 10 µF / 100 V / X7S;
- C10 = Taiyo Yuden LMK325B7476KM-PR / current number MSASL32MSB7476KPNB25, 47 µF / 10 V / X7R;
- C3 = Murata GRJ21BC72A105KE11L, 1 µF / 100 V / X7S;
- C21 = Murata GCM188R71E105KA64J, 1 µF / 25 V / X7R;
- upstream C5 = 100 µF / 50 V bulk reservoir.

### VIN/VCC bypass sourcing status — resolved

Historical D012 called for an additional dedicated 1 µF / 100 V VIN capacitor, but D018 supersedes that interpretation. ST's VIN requirement is 1 µF or higher; current C1 = 10 µF / 100 V X7S already satisfies it. C3 = 1 µF / 100 V X7S remains the dedicated VCC bypass.

The redundant buck C22 was deliberately removed in commit `24a9170a`. Current C22 is exclusively the CP2102 REGIN 1 µF / 25 V capacitor.

## Live BOM TME status

As read on **2026-09-21**, the live Google Sheet `Filament Dryer Monitor — BOM finale Mouser`, tab **`BOM TME`**, is set to **one PCB for manual assembly** and contains 94 unique PCB-mounted refs in 57 procurement/stock rows. Of these, **43 rows / 61 refs** are marked `TME`, and **14 rows / 33 refs** are marked `In casa` (J5 plus 13 resistor groups). The generated `TME_IMPORT` tab contains the 43 current TME code/quantity rows; it is an **export view, not proof of shipping or payment**. The full reference/MPN comparison against the released schematic netlist and current suffixed production BOM found no missing or duplicate PCB-mounted refs in the 2026-09-19 audit. A separate 2026-09-21 check found **all 43 current `TME_IMPORT` catalog codes in the original TME order confirmation**: no additional on-PCB supplier line is absent from that order. This verifies code presence in the order, **not** shipment, receipt or every quantity/MPN on delivery. Count actual packs ordered/shipped separately: TME minimum packs can exceed one-board quantities.

The order was **placed and paid 2026-09-20**. Supplier confirmation initially marked C11 `CL21A226MAYNNNE` as `Disponibile a magazzino` (page 1, position 3). On 2026-09-21 the supplier reported a warehouse unit could not be located and is investigating; a separate automatic notice listed `settimana 48/2026` for C11 alone. The **remaining order's release/ship date has not been explicitly confirmed**. Supplier discussions mentioned a possible refund/reorder route, but **no C11 cancellation, substitute order or complete-order cancellation is authorized**. Wait for their definite warehouse answer; do not arrange a second paid shipment without user approval.

**C11 identity / design role:** the released PCB/schematic uses Samsung `CL21A226MAYNNNE` (22 µF, 25 V, X5R, 0805), tied between `3V3_MCU` and GND. This is an actual assembly part, not DNP and not a missing PCB designator. TDK `C2012X5R1C226M125AC` (TME catalog code `C2012X5R1C226MAC`), 22 µF / 16 V / X5R / 0805, is **only a candidate**. Although 16 V nominal exceeds 3.3 V, review usable capacitance under 3.3 V DC bias and exact product identity before approving an assembly/BOM substitution. Do not silently overwrite current C11 MPN or sheet until delivery/substitution is resolved.

The previous C22 duplication is closed: C1 = 10 µF / 100 V VIN, C3 = 1 µF / 100 V VCC, and **C15,C17,C21,C22** share the separate 1 µF / 25 V 0603 sourcing row; C22 is the CP2102 REGIN bypass.

## Footprint audit

The main package/pin-number audit remains the basis of the design.

Important non-trivial footprint decisions:

| Ref | Final MPN | Footprint decision |
|---|---|---|
| C5 | Panasonic EEEFK1H101P | Custom Panasonic size-F footprint, Ø8 × 10.2 mm, manufacturer land-pattern basis |
| J2 | GCT USB4216-03-A | Custom USB-C footprint with fully SMT shell stakes |
| L1 | Bourns SRN6045-150M | Custom footprint based on Bourns recommended PCB layout |
| U2 | Silicon Labs CP2102-GM | Custom QFN28 footprint based on Silicon Labs CP2102/9 package guidance |
| SW1–SW6 | GCT SWT0110-020010SSA | Custom footprint based on GCT mechanical drawing |
| BZ1 | Loudity LD-BZEL-T67-0808 | Custom footprint with conservative terminal lands |
| U5 | ST L7987L | SamacSys_Parts:SOP65P640X120-17N; HTSSOP-16 exposed pad; six peripheral GND/thermal vias, no via-in-pad |

### CP2102-GM footprint state

Current custom U2 footprint:

- pitch 0.50 mm;
- perimeter lands 0.95 × 0.28 mm;
- exposed pad 3.25 × 3.25 mm;
- footprint solder-mask expansion +0.06 mm;
- exposed-pad paste split into 3 × 3 apertures of 0.9 × 0.9 mm.

Current REGIN bypass:

- C22 = 1 µF / 25 V / X7R / 0603;
- Murata GCM188R71E105KA64J;
- connected between 3V3_MCU and GND.

### U5 exposed-pad / assembly state

U5 pad 17 is 3.2 × 3.2 mm on B.Cu. The implemented thermal/GND path uses six through vias, each 0.60 mm diameter / 0.30 mm drill, immediately outside the pad in two rows of three. The vias are deliberately not placed inside the solderable EP, avoiding open via-in-pad solder-wicking risk.

The prototype assembly method is hand assembly: very light pre-tin on the power pad, flux and hot air. Therefore the full B.Paste shape in the KiCad footprint does not control the planned prototype solder volume and is not a release blocker. If the process changes to stencil/reflow or external PCBA, paste aperture and via treatment must be reopened for that process.

### Strict symbol/pin-numbering audit

The earlier audit corrected and retained:

- D1 = BZX84C15-7-F mapping;
- Q5 = IRLML2060TRPBF mapping;
- U2 = classic CP2102-GM symbol and custom QFN28 footprint.

Current USB board mapping is:

- U2 pin 4 = D+;
- U2 pin 5 = D−;
- U3 1↔6 = D+ channel;
- U3 3↔4 = D− channel;
- J2 A6/B6 = D+;
- J2 A7/B7 = D−.

The stored netlist was regenerated on 2026-09-17 and correctly maps J2 A6/B6 to D+ and A7/B7 to D−. Functional USB verification remains a first-board task.

## Physical/manufacturing items still open

- **Supplier fulfillment:** confirm TME warehouse outcome for C11, shipping of other available items, final shipped quantities, and payment/refund implications before modifying purchasing status.
- **Stock marked `In casa`:** inspect J5 and all 13 resistor BOM rows for correct values, packages and usable quantities; an `In casa` flag is not an inventory count.
- **Off-board items excluded from the 94 PCB refs:** the SSD1309 OLED for J4, SHT45 sensor for J3, independent heater cutoff/TCO in the HEATER+ wire, mating JST housings/contacts, leads/cable assemblies and mounting hardware. Verify real inventory, physical fit, pinout and wiring; do not infer they are included in the TME order.
- **Incoming bare board:** confirm JLC fab/shipment, inspect 91 × 52 mm PCB outline, four-layer build and solder mask/drilling; check U4 antenna edge, U2 EP solderability, J4/J5/JST mechanical alignment and BZ1 footprint before full population.
- **Hand assembly:** R5 remains **unfitted for first power-up**; C11 remains required for the completed design. Follow `docs/ASSEMBLY.md` and validate the 3.3 V regulator before enabling AutoEN/heater.

## Current stackup / plane decision

The 4-layer stackup remains:

- F.Cu 35 µm;
- 0.10 mm FR4;
- In1.Cu 35 µm **solid GND**;
- 1.24 mm FR4 core;
- In2.Cu 35 µm **solid GND**;
- 0.10 mm FR4;
- B.Cu 35 µm.

No internal 3V3/24 V power planes are used. Power distribution remains on external copper.

## Netclasses / USB

| Class | Clearance | Track | DP width / gap | Via dia/drill |
|---|---:|---:|---:|---:|
| Default | 0.20 mm | 0.25 mm | 0.20 / 0.25 mm default | 0.60/0.30 mm |
| Power_3V3 | 0.20 mm | 0.50 mm | — | 0.60/0.30 mm |
| Power_24V | 0.20 mm | 1.00 mm | — | 0.80/0.40 mm |
| Power_Heat | 0.30 mm | 1.50 mm | — | 0.80/0.40 mm |
| USB | 0.20 mm | **0.20 mm** | **0.20 / 0.25 mm** | 0.60/0.30 mm |

USB tuning profile USB_90R targets 90 Ω differential on B.Cu referenced to In2.Cu.

## Production release sequence

The 2026-09-17 production-source revision and ERC/DRC reports supersede the historical *pre-fabrication* checklist. For **this submitted prototype**, first confirm the manufacturer's current order/shipping status; then audit delivered bare PCBs and TME parts, close the C11 supply gap and off-board inventory, hand-assemble with R5 omitted initially, and perform first-board electrical/thermal/USB/safety checks. An actual **future hardware change** must restart schematic/PCB synchronization, ERC/DRC, production-output generation and BOM reconciliation under `AGENTS.md`; do not silently update already submitted fabrication data.

### J7 first-article recovery tooling — 2026-10-08

The fabricated board uses J7 = JST-GH BM02B-GHS-TBT, but the original eSUN NTC plug does not mate with it. J7 is already installed and will remain on the first article.

A PEBA micro-crimping kit/tool advertised for JST-GH 1.25 mm and 0.03–0.34 mm² conductors was purchased on 2026-10-08, with delivery expected Saturday 2026-10-10. The original NTC leads are believed to be about 30 AWG. Before modifying the dryer harness, perform a sacrificial GH crimp and check conductor crimp, insulation support, terminal shape, housing retention and pull strength. If acceptable, remove the incompatible original plug and terminate the NTC leads directly into a 2-position GH housing for J7.

This is first-article harness recovery, not a released PCB/BOM connector change. The J7 connector choice must be reviewed deliberately in the next hardware revision.

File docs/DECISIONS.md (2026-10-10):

# Engineering decisions

This file records durable project decisions. Do not silently replace them during later work. The actual KiCad sources remain authoritative for the current implementation; if new evidence forces a decision change, document the reason and update this file explicitly.

## D001 — L7987L buck architecture

**Status:** accepted / schematic signed off 2026-09-04.

The 24 V -> 3.3 V converter uses ST L7987L with an external TLV1701 + MMBT3904 AutoEN recovery circuit. The selected L7987L component values, compensation, ILIM and AutoEN thresholds are closed for schematic design. Reopen only if PCB/layout or physical validation provides a concrete reason.

Primary detailed record: `docs/BUCK_L7987L_DESIGN.md`.

## D002 — Four-layer stackup uses two solid GND inner planes

**Status:** accepted for current PCB layout.

- `In1.Cu` = full, continuous GND plane.
- `In2.Cu` = full, continuous GND plane.
- No 3V3 or 24 V distribution zones on either inner layer.
- Power distribution remains on the external layers with local copper/tracks as required.

Rationale: both outer routing layers receive a nearby continuous reference plane; the buck on B.Cu has In2 only 0.10 mm away. This also avoids return-current detours caused by split reference planes.

## D003 — L7987L PGND/SGND are current-path regions, not separate project nets

**Status:** accepted.

ST's power-ground / signal-ground guidance is implemented without splitting the internal GND planes and without creating separate electrical PGND/SGND nets.

Both are the same KiCad `GND` net. The distinction is made through B.Cu copper geometry and via placement:

- pulsed/high-current return: C1 negative, D7 anode, C10 negative;
- quiet/signal return: U5 pin 16 and exposed pad, C3 negative, C21 negative and sensitive control returns.

These paths use short local connections to the common solid GND planes. The high-current return geometry must not force switching current through the quiet feedback/compensation return region.

**Implementation clarification:** a continuous B.Cu PGND strip physically joining C1− to D7/C10− is not a project requirement. The high-current pads may enter the same solid inner GND planes through short nearby GND vias, provided the via placement and local copper keep the pulsed return current out of the quiet local return region. Do not move C21 merely to create a superficial PGND corridor across U5.

## D004 — Buck is implemented on B.Cu

**Status:** accepted/current implementation.

U5 and the new buck/AutoEN block are on B.Cu. In2 is therefore their nearest continuous GND reference plane. Local buck power copper/zones are also developed on B.Cu.

## D005 — ST reference layout controls buck placement topology

**Status:** accepted.

Use the ST L7987L datasheet and STEVAL-ISA198V1 layout/Gerbers as the primary layout reference, adapted to the project's four-layer stackup and actual footprints.

Current placement priorities:

- C3 = 1 µF local VIN/VCC bypass, closest practical connection to VIN/VCC;
- C1 = 10 µF main input ceramic, on the same VIN side and may be slightly farther out than C3;
- C6 = 100 nF BOOT-LX capacitor, very short BOOT/LX connection;
- D7/L1/LX copper form the switching region;
- C10 is the main pre-bead output capacitor;
- FB/COMP network remains compact and away from the switching/high-current region;
- C21 remains close to VBIAS.

In the current physical board view, the U5 VIN/VCC side is the **left side of the chip**. Do not reverse this based on top/bottom mirroring arguments.

## D006 — LX is controlled geometrically, not by a generic wide netclass

**Status:** accepted.

Do not create a generic wide `LX` netclass simply because it is a power node. Keep the switch-node copper short and controlled, with only the area needed to connect U5 LX, D7 cathode, C6 bootstrap return and L1 input. Minimize unnecessary switch-node area.

## D007 — Current power/default netclasses accepted; USB differential geometry remains open

**Status:** accepted; USB geometry closed 2026-09-16.

Accepted classes:

| Class | Clearance | Track | Via dia/drill |
|---|---:|---:|---:|
| Default | 0.20 mm | 0.25 mm | 0.60/0.30 mm |
| Power_3V3 | 0.20 mm | 0.50 mm | 0.60/0.30 mm |
| Power_24V | 0.20 mm | 1.00 mm | 0.80/0.40 mm |
| Power_Heat | 0.30 mm | 1.50 mm | 0.80/0.40 mm |
| USB | 0.20 mm | **0.20 mm** | 0.60/0.30 mm |

USB differential routing uses:

- signal layer B.Cu;
- nearest reference In2.Cu;
- 0.10 mm FR4 dielectric, Er 4.5 as entered in KiCad;
- target 90 Ω differential;
- DP width 0.20 mm;
- DP gap 0.25 mm;
- tuning profile `USB_90R`.

USB net names are `USB_D+`, `USB_D-`, `USB_CONN_D+`, `USB_CONN_D-`. Do not revert to `USB_DP`/`USB_DM`, because KiCad differential-pair recognition depends on a shared basename with +/− or P/N suffixes.

## D008 — Bottom-side orientation checks must use transformed/absolute geometry

**Status:** process rule.

Never recommend a B.Cu component rotation based only on raw local pad coordinates from the `.kicad_pcb` text. KiCad's bottom-side transform must be accounted for.

Use one of:

- KiCad/pcbnew absolute global pad positions;
- the actual board view with pad numbers/nets visible;
- another KiCad-derived read-only report that applies the correct transform.

This rule was added after a previous manual-coordinate review produced incorrect rotation recommendations.

## D009 — Hardware Design Manual is a read-only review framework

**Status:** accepted.

The external Hardware Design Manual is used as a source-agnostic engineering checklist/reference. Do not modify it during normal Filament Dryer repository work. Device-specific manufacturer documentation and standards take precedence for device-specific requirements.

## D010 — Production release requires fresh DRC and regenerated outputs

**Status:** accepted.

The historical `hardware/DRC.rpt` is not a release gate for the current PCB. No fabrication release until the current routed PCB has a fresh reviewed DRC and production Gerbers/BOM/CPL/netlist are regenerated from that same revision and reconciled with the purchasing BOM.

## D011 — Existing schematic review remains closed during PCB work

**Status:** accepted.

PCB placement/routing refinements that do not change electrical topology/component values do not reopen schematic sign-off. If layout forces an electrical or component change, explicitly reopen the relevant schematic-review gate, update the schematic/netlist first, then resynchronize the PCB and documentation.

## D012 — Historical dedicated second 1 µF VIN bypass

**Status:** superseded by D018 on 2026-09-16; implementation had already been removed in commit `24a9170a` on 2026-09-11.

D012 originally interpreted the L7987L datasheet as requiring two additional dedicated
1 µF / 100 V capacitors, one for VIN and one for VCC, and historical reference C22 was
added on `24V_PROT`.

That interpretation was overly strict because the datasheet requirement on VIN is **1 µF or
higher**, not specifically an additional 1 µF part. The existing local C1 = 10 µF / 100 V
ceramic already satisfies the VIN-to-power-GND requirement. C3 = 1 µF / 100 V remains the
dedicated VCC-to-IC-GND bypass.

D018 records the corrected durable decision. Do not re-add the historical buck C22 unless
new layout/measurement evidence creates a separate need for additional local input capacitance.

## D013 — AutoEN is required; validated failure mechanism is foldback lock

**Status:** accepted. Supersedes the rationale recorded in `BUCK_L7987L_DESIGN.md` section 11.

A datasheet-only review argued that the L7987L handles a persistent output fault natively
via pulse-by-pulse OCP, pulse skipping and FB foldback, and that AutoEN might therefore be
redundant complexity protecting against a simulation artifact.

Simulation on 2026-09-09 disproved that argument. The device protections are present and
work as documented, but recovery does not occur: foldback holds the output at ~1.5 V, which
keeps FB at ~0.36 V, below the 400 mV release threshold, indefinitely. Full detail in
`BUCK_L7987L_DESIGN.md` section 11.1.

AutoEN stays. Two of the three objections raised during that review were withdrawn on
evidence; the third — failure direction of U1 — is addressed by assembly order (D014).

Process note: the existing simulation evidence was the strongest available and should have
been examined before a datasheet argument was built against a closed decision.

## D014 — R5 unpopulated for initial bring-up

**Status:** accepted.

R5 (100 kΩ, TLV1701 open-collector pull-up) is not fitted at first assembly. A missing or
badly soldered U1 otherwise holds EN low through R5/Q7 and the board produces no 3.3 V rail,
which at first power-up is indistinguishable from a buck failure.

With R5 absent, R30 holds the Q7 base at ground and EN is free. R5 is fitted after the
regulator is confirmed working. No schematic or netlist change; the schematic carries a
`DNP at first assembly` note on R5 and the procedure lives in `docs/ASSEMBLY.md`.

## D015 — CP2102-GM land pattern, mask, paste and REGIN bypass

**Status:** accepted 2026-09-16.

The classic CP2102-GM QFN28 footprint is implemented as a custom project footprint with:

- 0.50 mm perimeter pitch;
- perimeter lands 0.95 × 0.28 mm;
- exposed pad 3.25 × 3.25 mm;
- footprint solder-mask expansion +0.06 mm;
- exposed-pad paste split into a 3 × 3 matrix of 0.9 × 0.9 mm apertures.

This follows the Silicon Labs CP2102/9 package guidance while preserving a practical solder-mask web.

REGIN is supplied from `3V3_MCU`. A local 1 µF / 25 V X7R 0603
`GCM188R71E105KA64J` is added in parallel with the existing local 100 nF decoupling.
The current schematic/PCB reference is C22.

Historical D012 also used the reference C22 for a redundant buck VIN bypass. D018 supersedes that
decision, so there is no remaining reference collision: current C22 is correctly reserved for CP2102
REGIN.

## D016 — USB ESD/channel mapping and Type-C duplicated-pad crossover

**Status:** accepted 2026-09-16.

USB data routing is kept on B.Cu as a differential pair for the long CP2102-to-ESD run.
The ESD protector channels are used as:

- pin 1 ↔ pin 6 = D+ channel;
- pin 3 ↔ pin 4 = D− channel;
- pin 2 = GND;
- pin 5 = USB_VBUS.

USB-C receptacle mapping remains standards-correct:

- A6/B6 = D+;
- A7/B7 = D−.

To preserve the clean no-via long pair from U2 to U3, the short connector-side duplicated-pad
fanout is allowed one local crossover: D+ uses two short signal vias and a short F.Cu bridge;
D− remains on B.Cu. A nearby GND stitching via provides a short reference transition between
In2 and In1. Do not move the layer change into the long U2→U3 pair merely to avoid the short
Type-C breakout crossover.

## D017 — External power-distribution copper policy

**Status:** accepted 2026-09-16.

Power distribution remains on the external copper layers; D002's two solid internal GND planes are unchanged.

- `/Power/3V3_BUCK`: use compact local copper around the buck output, C10, L1 and FB1 path. It is not a board-wide power plane.
- `3V3_MCU`: the normal distribution method may remain the existing **0.50 mm Power_3V3 traces** after FB1. Local copper pours are optional where they materially improve connection geometry; a broad 3V3_MCU plane is not required.
- `24V_PROT`: wide traces and/or local pours are appropriate where load current and voltage drop justify them.
- Fast switched nodes, especially L7987L `LX`, must keep copper area only as large as required for the current path. Heater/fan switched-node copper should likewise not be enlarged without a current/thermal reason.
- The distributed capacitance between an external DC power pour and the adjacent solid GND plane is not, by itself, a reason to avoid the pour. The more important parasitic-capacitance/EMI concern is excessive area on fast switch nodes.
- Do not let optional power pours crowd the controlled USB differential pair or violate the ESP32 antenna keepout.

This decision defines the default layout policy; it does not require replacing already-correct power traces with pours merely to increase copper area.

## D018 — L7987L VIN/VCC local ceramic requirement satisfied by C1 + C3

**Status:** accepted 2026-09-16; supersedes D012.

Manufacturer guidance requires a ceramic capacitor of **1 µF or higher** across VIN and
power GND and another of **1 µF or higher** across VCC and IC/signal GND, placed as close as
practical to the L7987L.

The current implementation satisfies this without an extra dedicated VIN 1 µF capacitor:

- C1 = 10 µF / 100 V X7S is the local VIN-to-power-GND ceramic and exceeds the ≥1 µF requirement;
- C3 = 1 µF / 100 V X7S is the local VCC-to-IC-GND bypass.

The additional buck C22 introduced in commit `6c6414b3` was therefore redundant and was
deliberately removed in commit `24a9170a` ("Removed C22"). Current reference C22 is used
only for the CP2102 REGIN 1 µF / 25 V bypass.

This decision depends on preserving C1 and C3 as genuinely local bypass components during
final layout review. It does not relax the requirement for short VIN/power-GND and
VCC/signal-GND high-frequency current paths.

## D019 — U5 exposed-pad thermal/GND implementation uses 3+3 peripheral vias

**Status:** accepted 2026-09-16; implementation already present since commit `c9dc4129`.

U5 pad 17 is the 3.2 × 3.2 mm GND/SGND exposed pad on B.Cu. The project deliberately does **not** use via-in-pad for U5. The thermal/GND path is implemented with six through vias immediately outside the exposed pad:

- via diameter 0.60 mm;
- drill 0.30 mm;
- three vias in a row immediately above U5;
- three vias in a row immediately below U5;
- all six are on GND and connect the external copper to the internal GND planes.

The current board coordinates confirm the two rows at approximately y = 82.9 mm and y = 87.35 mm around U5 centered at approximately `(174.649, 85.116)`. This keeps open vias out of the solderable exposed pad while retaining a short thermal and electrical path to the planes.

The planned prototype assembly process is manual: lightly pre-tin the exposed pad, apply flux, place U5 and solder with hot air. Under this process the footprint's full B.Paste shape is not used to meter solder paste and is therefore not a release blocker. If the process changes to stencil/reflow or external PCBA, reopen the paste-aperture and via-treatment decision for that manufacturing process.

First-board U5 temperature measurement remains mandatory validation. It does not mean the PCB thermal-via implementation is unfinished.

## D020 — Correct ESP32 auto-program collector mapping in next hardware revision

**Status:** accepted 2026-10-04 from first-article measurement and successful bodge validation.

The released board's CP2102 DTR/RTS cross-coupled Q2/Q3 auto-program network produces the opposite EN/IO0 truth-table behavior required for ESP32 automatic download entry. On the released hardware, Q2 collector drives IO0 and Q3 collector drives EN. Scope capture during esptool connection showed IO0 returning high before EN was released, so the ESP32 did not sample GPIO0 low at reset release.

The first-article correction was validated by crossing only the collector destinations:

- Q2 collector -> **EN**;
- Q3 collector -> **IO0**.

With that bodge and a 24 V bench current limit of 100 mA, no-button Arduino/esptool upload completes normally, including automatic connection, stub execution, flash verification and `Hard resetting via RTS pin...`.

Therefore the next deliberate schematic/PCB revision must implement the corrected collector mapping above, then regenerate the netlist, ERC, DRC and production outputs from the same revision. Do not silently modify the already-fabricated release checkpoint; the bodged first article remains the physical validation evidence for this correction.

## D021 — D3 is an internal diagnostic LED with defined firmware patterns

**Status:** accepted 2026-10-04 after Gate 4B first-article validation.

D3 is driven from ESP32 GPIO26 through R18 and is not visible from outside the intended enclosure. It is therefore **not a user-interface status indicator** and should not be relied upon to communicate normal operating state to the end user. User-visible state belongs on the OLED and, where appropriate, the buzzer.

D3 is reserved as an internal service/diagnostic indicator for firmware bring-up and troubleshooting. Future application firmware should use these patterns:

| Diagnostic state | D3 pattern |
|---|---|
| Early boot / initialization | solid ON from application startup until initialization completes |
| Normal application running | heartbeat: ~100 ms ON every 2 s |
| Recoverable peripheral/sensor warning | double pulse: ~100 ms ON, 100 ms OFF, 100 ms ON, repeated every 2 s |
| Safety/fault state that inhibits controlled outputs | repeating 250 ms ON / 250 ms OFF |
| Firmware halted before LED initialization, board unpowered, or GPIO26 unavailable | LED remains OFF; this state is intentionally not uniquely distinguishable by D3 alone |

A solid ON indication persisting well beyond normal initialization therefore also acts as a useful clue that startup has stalled. The safety-fault LED pattern is diagnostic only: heater/fan safety behavior must never depend on the LED itself.

Gate 4B first-article testing confirmed D3 can be controlled correctly from GPIO26.

## D022 — Front-panel V1 interaction model

**Status:** accepted 2026-10-08 after first-article validation of OLED, buttons and buzzer.

The local front panel is the primary standalone operating interface; ordinary drying cycles must not require Wi-Fi, a phone or the web UI. Detailed behavior is defined in `docs/UI_SPEC.md`.

Durable V1 rules:

- ON/OFF is a **cycle-control** button, not a hardware power switch. On boot/reset the application enters safe `STANDBY`; an interrupted cycle is not automatically resumed.
- User-facing states are `BOOT`, `STANDBY`, `SETUP`, `DRYING`, `COMPLETE` and overriding `FAULT`. A later explicit `COOLDOWN` state may be added if final fan-control policy requires it.
- Normal V1 cycle settings are target chamber temperature, duration and fan `AUTO`. Material profiles are deferred until their values and control/safety implications are deliberately agreed.
- Relative humidity is displayed/logged but is **not by itself a V1 automatic end-of-cycle criterion**.
- During `SETUP`, M selects the next field and UP/DOWN adjust it with long-hold autorepeat. During `DRYING`, parameters are locked in V1; M changes information pages and ON/OFF requires a long press (nominally ~1.5 s, tunable) to stop the cycle.
- If the OLED has entered standby sleep, the first button press only wakes the display and is consumed.
- `FAULT` overrides normal UI presentation. M may mute/acknowledge the audible alarm, but muting never clears the fault or re-enables the heater. Reset is permitted only after the underlying condition clears and the independent safety logic accepts it.
- The buzzer provides event feedback: short start confirmation, one-shot ascending completion melody, warning tones and a distinctive repeating fault alarm; loudness is software controlled approximately as OFF/LOW/MED/HIGH and must be empirically tuned.
- D3 remains the hidden internal diagnostic/service LED defined by D021; it is not a user-facing normal status indicator.
- UI/menu code is architecturally separate from cycle control and the heater safety controller. No menu, display or buzzer state may bypass heater safety.

Final temperature/time ranges, NTC thresholds, control gains, fan AUTO/cooldown policy, material presets and exact graphics remain intentionally open pending physical validation.

## D023 — Slewform startup branding and power-on chime

**Status:** accepted 2026-10-08.

At application startup/reset, the OLED presents Slewform branding.
On 2026-10-10 the user approved replacing the single logo+wordmark image
with two **separate display phases** from the unmodified canonical
`firmware/assets/slewform/Slewform_logo.svg`:

- **0–1.5 s:** large stationary upper symbol with roots growing outward;
- **1.5–2.1 s:** the complete symbol remains visible, still silent;
- **2.1–3.5 s:** only the centered SLEWFORM wordmark, with no symbol.

The original rising power-on chime now starts **only when the solo wordmark
appears**, at 2.1 s. The previous 3.5 s total BOOT interval is preserved.
Active generated asset: `firmware/assets/slewform/slewform_animation_compact.h`;
generator: `firmware/assets/slewform/generate_animation_compact.py`.
The old `slewform_logo_128x64.h` remains available as a legacy static splash.

The splash is paired with a short **original two-step rising power-on chime** whose design intent is the concise, recognizable feel of a classic handheld-console startup. It must not be a note-for-note reproduction of the Nintendo Game Boy startup sound.

First-article use testing found the original ~1.5 s splash too brief; the accepted current timing is **3.5 s**. Heater/fan safe output state and other safety-critical initialization take precedence over branding: the splash/chime must never delay forcing controlled outputs safe.

The first SAFE BRING-UP implementation is in `firmware/firmware.ino` and `firmware/Buzzer.h`.

## D024 — Setup back action; contextual button-label trial rejected

**Status:** revised 2026-10-08 after first layout review.

After live testing of the SAFE BRING-UP UI, the interaction felt somewhat indirect. The accepted usability change is:

- in `SETUP`, **M short = next field** and **M long = cancel/back to STANDBY**; ON/OFF remains dedicated to starting the cycle.

A trial of small context-sensitive labels aligned with the four physical buttons (`START`, `SET`, `NEXT`, `+`, `-`, `STOP`, `PAGE`) was implemented briefly, then **rejected** because the 128×64 display is too constrained and the labels compete with or overlap more important content.

Do not reserve OLED space for persistent button hints in the normal V1 screens. Primary measurements, cycle state and fault information take priority.

## D025 — SAFE BRING-UP fan policy and persisted local settings

**Status:** accepted for first-article application testing 2026-10-08.

The already-validated fan may now operate during application DRYING test cycles while the heater remains hard-locked OFF.

Temporary bring-up fan policy:

- PWM frequency: 25 kHz;
- start of cycle: 100% duty for 1 s;
- after kick-start: 40% duty;
- stop/complete/fault: fan OFF;
- no post-cycle cooldown yet.

The 40% run point intentionally retains margin over the measured first-article thresholds (25% first tested start-from-rest, 15% lowest tested sustained operation). These values are **not** the final FAN AUTO policy.

Application architecture is split into dedicated cycle, fan and safety controllers. The current safety controller continuously forces HEATER_PWM LOW and does not expose any heater-enable path.

Local settings are persisted in ESP32 Preferences/NVS:

- last target-temperature UI value;
- last cycle duration;
- buzzer volume OFF/LOW/MED/HIGH;
- key-click preference.

Writes are performed only when values have changed and a setup/settings flow is committed, rather than on each autorepeat increment. Active-cycle/running state is deliberately not persisted, so reset/power loss cannot cause an automatic cycle restart.

## D026 — Reproducible Slewform OLED bitmap conversion

**Status:** implemented for first-article visual validation 2026-10-10.

This records the earlier combined static logo conversion. D023 was
subsequently revised on 2026-10-10 to show the symbol and wordmark on
separate screens. `generate_logo.py` builds a 90×60
XBM bitmap from the repository's vector source by combining the source-colored
geometry into a single alpha mask, rendering at high resolution, filtering
and thresholding to one bit. Three reproducible thresholds are provided:
light 165, balanced 115, strong 72. The balanced version is currently selected,
pending physical OLED inspection. This historical static bitmap preserves
`slewform_full_logo` for reference but is no longer selected by the UI. The
canonical SVG is unchanged; test the animated graphics on the target display
before calling the artwork final. No heater-control behavior is changed.

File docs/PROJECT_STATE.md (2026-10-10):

# Project state

Checkpoint date: **2026-10-04**  
Active hardware branch: **`main`**  
Fabrication-source checkpoint (before documentation updates): **`74a3000127371ac6c3b3b7197f9036dec5b58eef`** (`Production files`, 2026-09-17). Documentation-only commits after this checkpoint do not change the released hardware.

## Executive state

The L7987L + AutoEN revision was released for a **bare-board, manual-assembly prototype**. The stored current KiCad reports date from 2026-09-17: ERC **0 errors / 0 warnings**; DRC **0 active errors / 0 unconnected pads / 0 footprint errors**, with **one excluded** U4 B.Silkscreen-to-board-edge warning. The stored netlist was regenerated on 2026-09-17 and has the corrected USB-C D+/D− mapping. The released production BOM and position file are `hardware/production/Filament_Dryer_Monitor_bom.csv` and `hardware/production/Filament_Dryer_Monitor_positions.csv`; the unsuffixed `hardware/production/bom.csv` / `positions.csv` are legacy AP66200-era exports and **must not** be used for the current design.

Gerbers/drills were uploaded to JLCPCB for bare-PCB production. Its production/CAM package was received and checked against the uploaded Gerbers in the order discussion. **On 2026-10-01 the user reported that the bare PCBs and component shipment had arrived.** First-article hand assembly and staged bring-up are now in progress. Gate 1A, isolated buck, AutoEN normal-operation, 3V3_MCU rail-link, and Gate 3 MCU power/reset/boot checks have passed as recorded below. USB enumeration at Gate 3 currently fails at the device-descriptor stage. No PCBA/stencil service is planned; all components are hand-assembled.

**Procurement (2026-09-21):** the live `BOM TME` reconciles to the current production BOM/netlist with 94 PCB-mounted component references for one assembled board: 61 references in 43 TME purchase rows and 33 references on 14 rows marked `In casa`. TME order was placed 2026-09-20; shipment and receipt are unconfirmed. **C11, Samsung CL21A226MAYNNNE (22 µF / 25 V X5R / 0805), is an open supply issue.** The order confirmation listed it as available; TME later reported its warehouse unit could not be located and is searching for it. TME offered a cancellation/refund or reordering route, but no cancellation, replacement or revised PCB MPN has been authorized. TME's later "week 48/2026" delivery notification does not establish that the rest of the order is delayed; dispatch of other in-stock items remains **unconfirmed**.

A candidate alternative mentioned by TME is TDK `C2012X5R1C226M125AC` (TME catalog code `C2012X5R1C226MAC`), 22 µF / 16 V X5R / 0805. It is **not ordered, not installed and not a committed BOM change**. The preferred next step is TME's definitive warehouse and shipping reply, not a second paid-shipping order. Keep the current C11 in schematic and BOM until an actual supply decision is reached.

**Outside the PCB purchasing BOM:** the OLED fitted at J4, off-board SHT45 sensor, independent heater thermal cutoff, mating connector housings/terminals/cables, and mounting hardware need a separate inventory check; their physical availability is not established by the 94-reference PCB BOM. J5 and 13 resistor rows are marked `In casa` in the sheet, but their actual packages/values/quantities still need confirming at assembly. Follow `docs/ASSEMBLY.md`: R5 is deliberately unpopulated at first 3.3 V power-up and fitted after the initial rail check.

The historical D012/C22 buck-bypass conflict remains closed (D018): C1 10 µF / 100 V covers VIN, C3 1 µF / 100 V covers VCC, and C22 now belongs exclusively to the CP2102 REGIN bypass. No circuit decision is changed in this documentation checkpoint.

## Sources inspected for this checkpoint

- Active branch `pcb/l7987l-layout`, fabrication-source commit `74a3000`; `AGENTS.md`, `README.md`, `docs/PROJECT_STATE.md`, `docs/DECISIONS.md`, `docs/TODO.md`, `docs/ASSEMBLY.md`, `docs/BUCK_L7987L_DESIGN.md`, `hardware/docs/PROCUREMENT.md`.
- Actual design/production source: `hardware/Power.kicad_sch`, `hardware/MCU.kicad_sch`, `hardware/Filament_Dryer_Monitor.net` (2026-09-17), `hardware/Filament_Dryer_Monitor.kicad_pro`, the `hardware/Filament_Dryer_Monitor.kicad_pcb` identity and released production files, `hardware/ERC.rpt` and `hardware/DRC.rpt` (2026-09-17). The whole PCB layout was not re-reviewed in this documentation-only checkpoint; the stored DRC and prior CAM review are the cited evidence.
- Live Google Sheet `Filament Dryer Monitor — BOM finale Mouser`, tabs `BOM TME` and `TME_IMPORT`, inspected 2026-09-21; original TME order confirmation dated 2026-09-20 and supplier correspondence of 2026-09-21.

The actual KiCad source files override descriptions, and supplier order/ship status must be confirmed directly rather than inferred from purchase-list availability.

## Electrical design state

The accepted L7987L design basis remains:

| Ref | Value / part | Function |
|---|---|---|
| U5 | ST L7987L | 24 V to 3.3 V asynchronous buck |
| U1 | TLV1701AIDBVR | AutoEN fault comparator |
| Q7 | MMBT3904 | EN pull-down |
| L1 | SRN6045-150M, 15 µH | Buck inductor |
| D7 | PMEG6030EP,115 | Catch Schottky, Nexperia 60 V / 3 A, CFP5/SOD-128 |
| C1 | 10 µF / 100 V X7S | Main local input ceramic |
| C3 | 1 µF / 100 V X7S | Current local VIN/VCC bypass present in source |
| C10 | 47 µF / 10 V X7R | Main pre-bead output capacitor |
| C21 | 1 µF / 25 V | VBIAS bypass |
| R4 | 47 kΩ | FSW, about 516 kHz nominal |
| R29 | 47.5 kΩ | ILIM, about 1.705 A nominal |
| R33/C9/C8 | 16 kΩ / 18 nF / 39 pF | Type-III compensation branch |
| R35/C20 | 1.13 kΩ / 560 pF | Type-III compensation branch |
| R36/R34 | 49.9 kΩ / 16 kΩ | Feedback divider, about 3.295 V nominal |

Output architecture remains `3V3_BUCK -> FB1 -> 3V3_MCU`. `PGOOD` and `SYNCH` remain intentionally NC.

The 2026-09-04 design calculations/review remain accepted: nominal ILIM about 1.705 A, engineering selection envelope about 1.42–2.15 A, and recorded compensation simulation about 59.1 kHz crossover / 64.9° phase margin / 19.6 dB gain margin.

### VIN/VCC local ceramic requirement — resolved

The original D012 interpretation treated ST's VIN and VCC bypass guidance as requiring two additional dedicated 1 µF / 100 V parts. The later review corrected that interpretation.

ST requires:

- a ceramic capacitor of **1 µF or higher** across VIN and power GND, close to U5;
- a ceramic capacitor of **1 µF or higher** across VCC and IC/signal GND, close to U5.

Current implementation:

- **C1 = 10 µF / 100 V X7S** is the local VIN ceramic and therefore already exceeds the VIN-side minimum;
- **C3 = 1 µF / 100 V X7S** is the local VCC bypass.

The extra 1 µF / 100 V buck C22 added in commit `6c6414b3` was redundant and was deliberately removed in commit `24a9170a`. Decision D012 is retained only as historical context and is superseded by D018 in `docs/DECISIONS.md`.

Current C22 belongs to the MCU sheet and is the CP2102 REGIN 1 µF / 25 V capacitor.

## MCU / USB state

### CP2102-GM

U2 is the classic CP2102-GM QFN28 implementation.

Current custom footprint state:

- perimeter pads: **0.95 × 0.28 mm**;
- exposed pad: **3.25 × 3.25 mm**;
- footprint solder-mask expansion: **+0.06 mm**;
- exposed-pad paste: **3 × 3 apertures, 0.9 × 0.9 mm**;
- U2 pad 3 and exposed pad 29 are GND.

The new REGIN decoupling capacitor is **C22 = 1 µF / 25 V / X7R / 0603, Murata `GCM188R71E105KA64J`**, connected between `3V3_MCU` and GND.

### USB differential routing

Accepted/configured USB geometry:

- signal layer: **B.Cu**;
- reference: **In2.Cu**;
- B.Cu-to-In2 dielectric: **0.10 mm FR4, Er 4.5**;
- target: **90 Ω differential**;
- track width: **0.20 mm**;
- differential gap: **0.25 mm**;
- tuning profile: **`USB_90R`**.

Current PCB mapping:

- U2 pin 4 = `USB_D+`;
- U2 pin 5 = `USB_D-`;
- U3 pin 1 ↔ pin 6 = D+ channel;
- U3 pin 3 ↔ pin 4 = D− channel;
- J2 A6/B6 = `USB_CONN_D+`;
- J2 A7/B7 = `USB_CONN_D-`;
- J2 GND pins and shield are GND.

U2 -> U3 D+/D− stays on B.Cu with **no vias**. On the short Type-C breakout, D+ uses **two signal vias** for the duplicated-pad crossover; D− remains on B.Cu. A nearby GND stitching via supports the reference-layer transition.

### Stored netlist is stale

`hardware/Filament_Dryer_Monitor.net` was regenerated on **2026-09-17 21:13:01** from the current schematic, after the earlier USB correction. The actual netlist contains J2 A6/B6 on `/MCU/USB_CONN_D+` and J2 A7/B7 on `/MCU/USB_CONN_D-`, consistent with the current schematic/board mapping above. The older warning about the 2026-09-16 reversed USB netlist is historical and **resolved**. USB enumeration and signal integrity still require first-board testing.

## PCB state

Current board file: `hardware/Filament_Dryer_Monitor.kicad_pcb`.

Current B.Cu/local-zone implementation includes:

- `24V_PROT` zones;
- local `/Power/3V3_BUCK` zone;
- local `3V3_MCU` zone;
- `/IO_Power/HEATER_SW` zone;
- controlled LX / `Net-(D7-K)` zone;
- local GND zones;
- full-board GND planes on In1.Cu and In2.Cu.

All nets are presently connected according to the fresh DRC. That closes the **connectivity/ratsnest** phase, not the engineering review/release phase.

### Power-distribution policy

Decision D017 records the power-copper policy for the current layout:

- `/Power/3V3_BUCK` stays a **compact local B.Cu copper area** around the buck output/C10/L1/FB1 path;
- `3V3_MCU` may remain **primarily 0.50 mm Power_3V3 traces after FB1**. The local zone currently present in the PCB is optional layout copper, not a requirement for a broad 3.3 V plane;
- `24V_PROT` may use wide traces and local pours where current/voltage-drop needs justify them;
- `LX` and other switched nodes remain geometrically compact;
- both inner layers remain uninterrupted GND.

Capacitance from an external DC power area to the nearby GND plane is not considered a reason to avoid the area. The relevant parasitic/EMI concern is excessive copper on fast switched nodes, plus any optional pour crowding the USB pair or ESP32 antenna keepout.

### U5 exposed pad — resolved for planned assembly

U5 is centered at approximately `(174.649, 85.116)` on B.Cu. Pad 17 is the **3.2 × 3.2 mm** GND/SGND exposed pad.

The accepted implementation is deliberately **not via-in-pad**. Six GND vias, each **0.60 mm diameter / 0.30 mm drill**, are placed immediately outside the pad in two rows of three:

- one row at approximately y = 82.9 mm;
- one row at approximately y = 87.35 mm;
- x positions around 173.75 / 174.65 / 175.55 mm.

This geometry was implemented in commit `c9dc4129` (`updated vias on U5 and D7`) and remains present in the current PCB. It gives the EP a short thermal/GND path to the internal GND planes without open vias directly under the solderable pad.

For the planned prototype process, U5 is hand assembled with a very light pre-tin on the exposed pad, flux and hot air. The current full-size B.Paste definition therefore does not control solder deposition and is **not a fabrication blocker** for this flow. If the process later changes to stencil/reflow or external PCBA, the paste aperture and via-treatment strategy must be reopened for that process.

First-board measurement of U5 temperature remains required, but that is prototype validation rather than unfinished PCB implementation. Decision D019 records this closure.

## Stackup / planes

| Layer | Copper / spacing | Role |
|---|---|---|
| F.Cu | 35 µm | front components/signals |
| dielectric 1 | 0.10 mm FR4, Er 4.5 | F.Cu to In1 |
| In1.Cu | 35 µm | **solid GND plane** |
| core | 1.24 mm FR4, Er 4.5 | inner separation |
| In2.Cu | 35 µm | **solid GND plane** |
| dielectric 3 | 0.10 mm FR4, Er 4.5 | In2 to B.Cu |
| B.Cu | 35 µm | back components/signals + local power copper |

Closed decision: **both internal layers remain continuous GND planes**. Power distribution stays on external layers.

## Netclasses

| Class | Clearance | Track | DP width / gap | Via dia/drill |
|---|---:|---:|---:|---:|
| Default | 0.20 mm | 0.25 mm | 0.20 / 0.25 mm default | 0.60/0.30 mm |
| Power_3V3 | 0.20 mm | 0.50 mm | — | 0.60/0.30 mm |
| Power_24V | 0.20 mm | 1.00 mm | — | 0.80/0.40 mm |
| Power_Heat | 0.30 mm | 1.50 mm | — | 0.80/0.40 mm |
| USB | 0.20 mm | **0.20 mm** | **0.20 / 0.25 mm** | 0.60/0.30 mm |

USB data nets are assigned to the USB class and use tuning profile `USB_90R`.

## ERC / CI state

Current stored `hardware/ERC.rpt` is dated **2026-09-17 22:18:03** and reports **0 errors, 0 warnings** (with the report's listed ignored check classes). No new ERC is claimed for documentation-only commits.

The branch-specific CI workflow trigger should be checked before assuming automatic ERC will run on documentation or future hardware changes; the successful stored report is the last confirmed check.

## DRC state

Current stored `hardware/DRC.rpt` is dated **2026-09-17 22:18:19**. It reports **0 active errors, 0 active warnings, 0 unconnected pads and 0 footprint errors**. One `silk_edge_clearance` warning for U4 B.Silkscreen touching Edge.Cuts is **explicitly excluded**, not an active defect. Check the released fabrication layers/board edge in the physical prototype; no DRC was rerun for documentation-only commits. The earlier 14-active-warning report from 2026-09-16 is obsolete.

The released bare PCB still requires incoming inspection and all first-board electrical, thermal and fault-recovery tests.

## Procurement/BOM reconciliation

The live Google Sheet `Filament Dryer Monitor — BOM finale Mouser`, tab `BOM TME`, was read on **2026-09-21**. Its 94 PCB-mounted references match the current released `hardware/production/Filament_Dryer_Monitor_bom.csv` and schematic netlist; no PCB-mounted ref or MPN discrepancy was found in the previous full 2026-09-19 audit. The sheet currently lists **61 PCB items across 43 supplier rows**, with **33 refs marked in house**; one PCB is selected for assembly. `TME_IMPORT` is the dynamically generated 43-row purchasing/export tab, **not an order-status ledger**.

The TME purchase was placed 2026-09-20; all **43 current `TME_IMPORT` supplier catalog codes** were found in the original order confirmation during a 2026-09-21 check (this does not verify shipment or received quantities). Its original confirmation lists C11 `CL21A226MAYNNNE` as `Disponibile a magazzino` (page 1, position 3), but TME later acknowledged the stocked unit is missing and is searching for it. Its week 48/2026 ETA is a supplier notice for **C11 alone**. Do not infer the delivery date of the remaining order from that notice. The supplier has **not confirmed** release of all other lines or resolution of C11. No cancellation/replacement has been authorized.

C11 is **required in the assembled design**: it is a 22 µF MLCC from `3V3_MCU` to GND. Current authorized MPN: Samsung `CL21A226MAYNNNE`, 25 V X5R 0805. The 16 V TDK candidate `C2012X5R1C226M125AC` / TME `C2012X5R1C226MAC` is a *candidate only*; verify stock, dimensions, DC-bias/usable capacitance and order resolution before installing or changing the purchasing BOM. There is no reason to change the PCB footprint based on the nominally identical 0805 size. Do **not** omit C11 for final assembly.

Do not treat the old unsuffixed `hardware/production/bom.csv` (legacy AP66200/CP2102N-era) as this design's current BOM. The suffixed export's `LCSC Part #` column is a mixed historical/supplier field; the **live Google Sheet's `Codice TME`** is authoritative for TME purchases. Reconcile actual deliveries (including supplier-imposed minimum quantities) against the TME order confirmation, not only the nominal per-board quantities.

Off-board OLED/J4, SHT45/J3, independent heater cutoff, mating housings/crimps/cable assemblies and mounting parts are **not included** in the 94-component PCB order. Treat them as inventory/assembly checks, not as newly selected PCB parts. See `hardware/docs/PROCUREMENT.md` for follow-up.

## Immediate handoff / next gates

1. Wait for TME's definitive result of the C11 warehouse search and a clear statement about shipping all other available order lines; do not cancel/reorder or silently replace the BOM until agreed.
2. Reconcile received TME packages against `BOM TME`, the confirmed order quantities and all 33 in-house refs. In particular, confirm the actual capacitor supplied for C11 before soldering.
3. Verify physical availability, pinout and fit of J4 OLED, external SHT45, thermal cutoff, mating connectors/cables and enclosure fasteners. The procurement sheet does not establish these are in house.
4. Inspect the received bare PCBs for mask, drills, component fit, exposed pads and assembly clearances; reconcile the received component packages/quantities against the released BOM before soldering.
5. Hand-assemble and bring up the first PCB following `docs/ASSEMBLY.md` (**R5 initially not populated**); verify 3.3 V, USB, sensor/display, buck temperature and fault handling before heater operation.
6. Keep experimental PCB changes and future-revision review separate from the already submitted fabrication revision; do not retroactively rewrite the released Gerber/netlist/BOM checkpoint without new evidence and a deliberate revision.
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

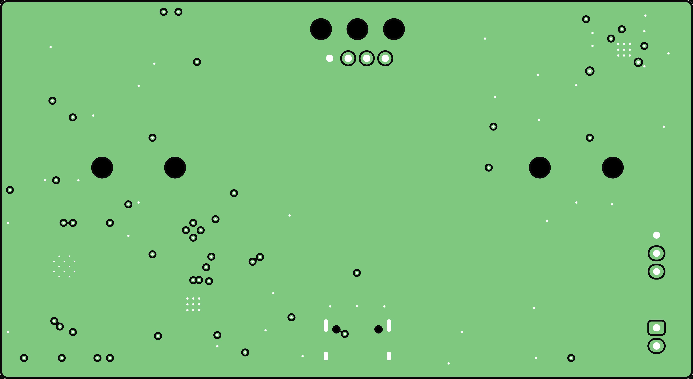
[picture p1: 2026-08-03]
hardware/review/Filament_Dryer_Monitor-In1_Cu.png

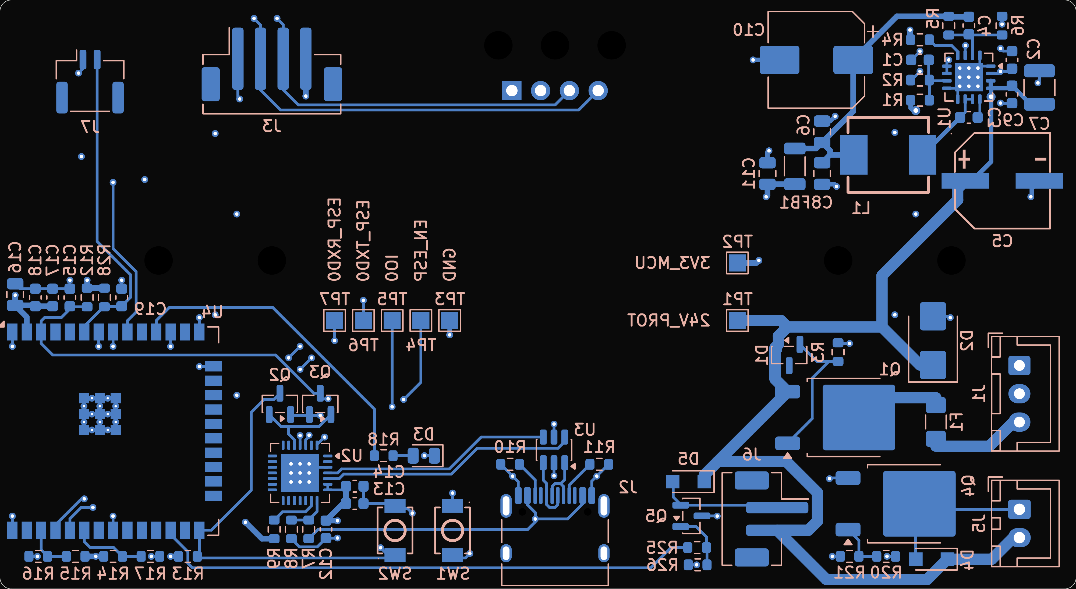
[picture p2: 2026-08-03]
hardware/review/Filament_Dryer_Monitor-B_Cu.png

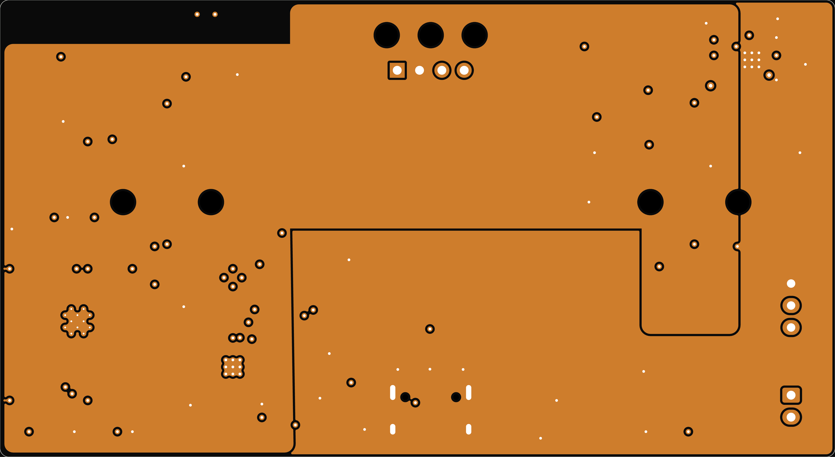
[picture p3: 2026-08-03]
hardware/review/Filament_Dryer_Monitor-In2_Cu.png

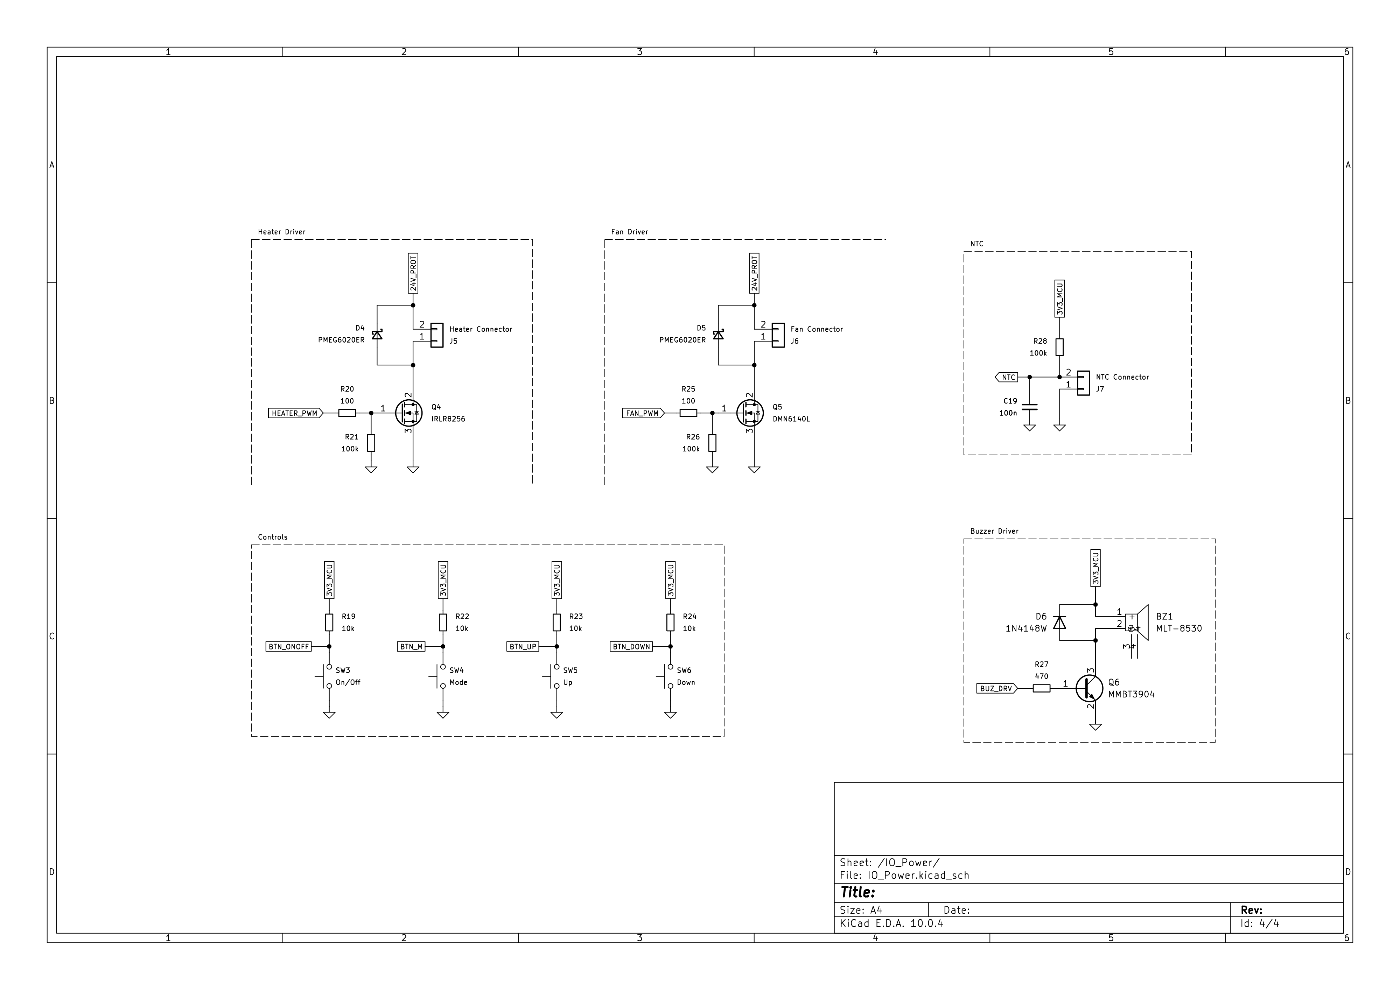
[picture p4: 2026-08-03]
hardware/review/Filament_Dryer_Monitor-IO_Power.png

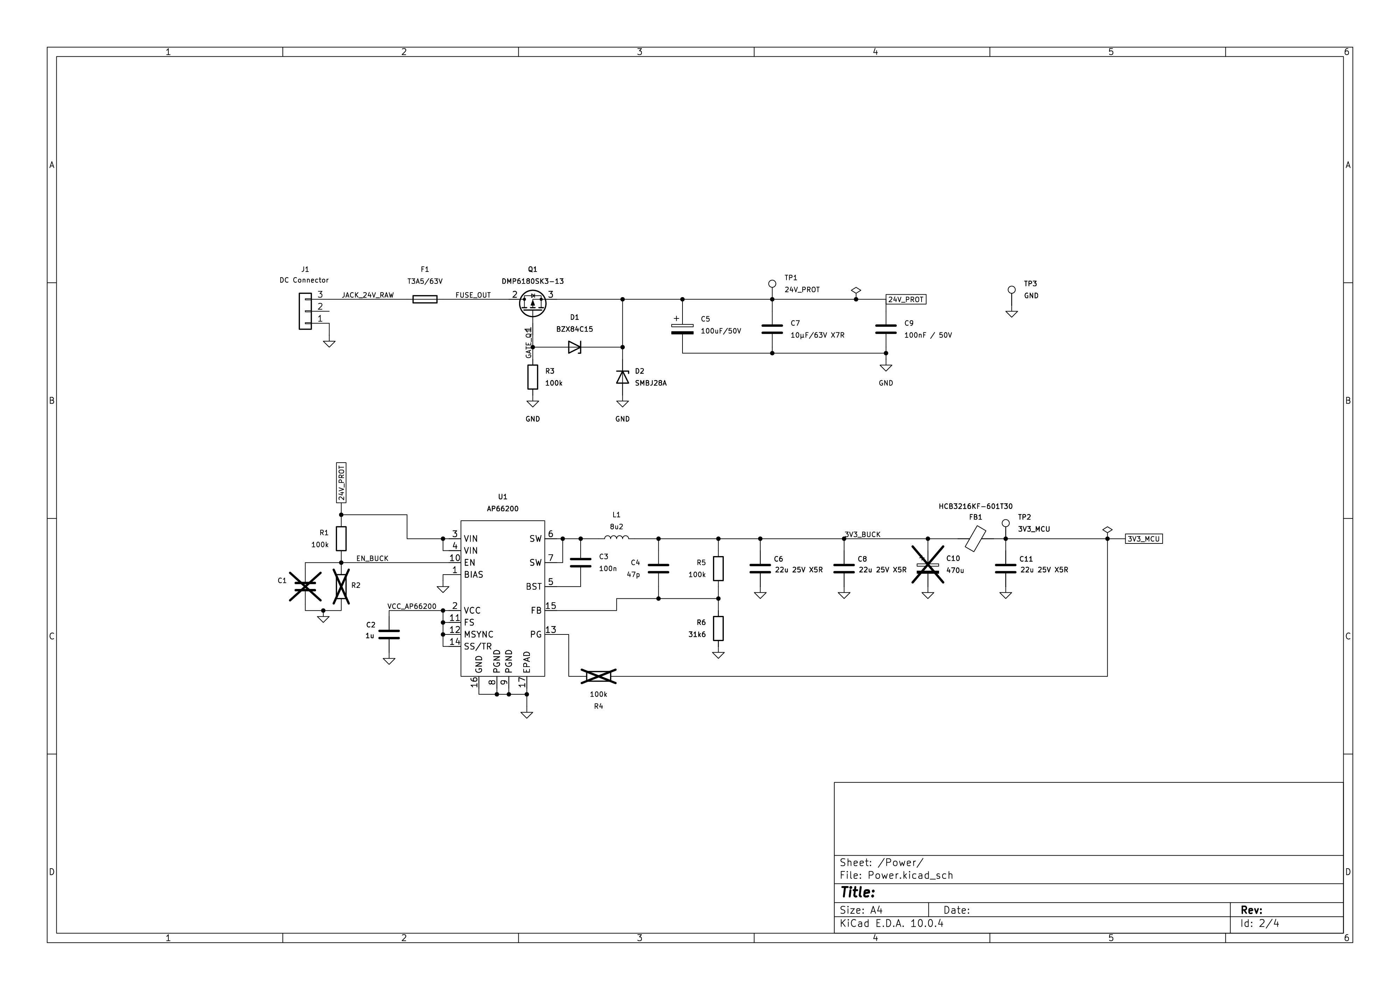
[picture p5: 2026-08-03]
hardware/review/Filament_Dryer_Monitor-Power.png

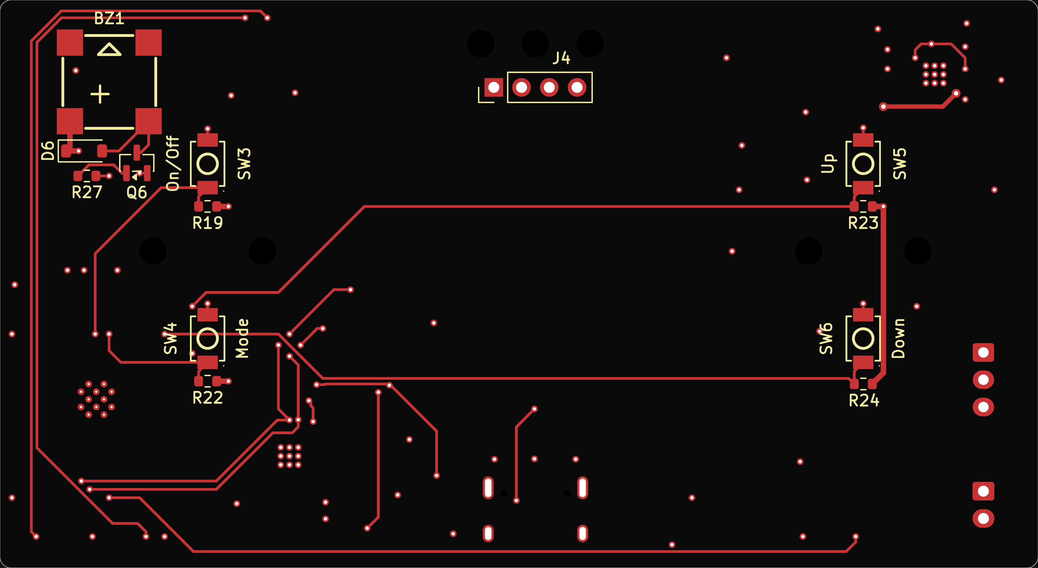
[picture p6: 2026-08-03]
hardware/review/Filament_Dryer_Monitor-F_Cu.png

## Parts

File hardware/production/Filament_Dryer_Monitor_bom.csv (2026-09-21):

Designator | Footprint | Quantity | Value | LCSC Part #
BZ1 | BUZ_Loudity_SMT67_8.5x8.5 | 1 | LD-BZEL-T67-0808 | LD-BZEL-T67-0808
C1 | 1210 | 1 | 10u | GRM32EC72A106KE05L
C10 | 1210 | 1 | 47u | LMK325B7476KM-PR
C11 | 0805 | 1 | 22u | C45783
C12 | 0603 | 1 | 4u7 | C19666
C13, C14, C18, C19 | 0603 | 4 | 100n | C14663
C15, C17 | 0603 | 2 | 1u | C5199872
C16 | 0805 | 1 | 10u | C15850
C2, C6 | 0603 | 2 | 100n | CC0603KRX7R9BB104
C20 | 0603 | 1 | 560p | 06035A561JAT2A
C21, C22 | 0603 | 2 | 1u | GCM188R71E105KA64J
C3 | 0805 | 1 | 1u | GRJ21BC72A105KE11L
C4 | 0603 | 1 | 33n | GCM188R71H333KA55D
C5 | CP_Panasonic_F_8x10.2 | 1 | 100u | EEEFK1H101P
C7 | 0805 | 1 | 330n | GRM219R71H334KA88D
C8 | 0603 | 1 | 39p | C0603C390J5GACTU
C9 | 0805 | 1 | 18n | GRM21B5C1H183JA01L
D1 | SOT-23 | 1 | BZX84C15-7-F | C500789
D2 | D_SMB | 1 | SMBJ28A | C96335
D3 | 0805 | 1 | LED_Small | C5569446
D4, D5 | Nexperia_CFP3_SOD-123W | 2 | PMEG6020ER | C98663
D6 | D_SOD-123 | 1 | 1N4148W | C81598
D7 | D_SOD-128 | 1 | PMEG6030EP | PMEG6030EP.115
F1 | 1206 | 1 | T3A/63V | C354897
FB1 | 1206 | 1 | BLM31KN601SH1L | C357023
J1 | JST_XH_B3B-XH-A_1x03_P2.50mm_Vertical | 1 | DC Connector | B3B-XH-A (LF)(SN)
J2 | USB_C_GCT_USB4216-03-A | 1 | USB_C_Receptacle_USB2.0_16P | USB4216-03-A
J3 | JST_PH_B4B-PH-SM4-TB_1x04-1MP_P2.00mm_Vertical | 1 | Sensor | B4B-PH-SM4-TB (LF)(SN)
J5 | JST_XH_B2B-XH-A_1x02_P2.50mm_Vertical | 1 | Heater Connector | Kit HALJIA XH-compatible 2P
J6 | JST_PH_B2B-PH-SM4-TB_1x02-1MP_P2.00mm_Vertical | 1 | Fan Connector | B2B-PH-SM4-TB (LF)(SN)
J7 | JST_GH_BM02B-GHS-TBT_1x02-1MP_P1.25mm_Vertical | 1 | NTC Connector | C161690
L1 | L_Bourns_SRN6045 | 1 | 15u | SRN6045-150M
Q1 | TO-252-2 | 1 | NTD20P06LT4G | C93034
Q2, Q3, Q6 | SOT-23 | 3 | MMBT3904 | C94514
Q4 | TO-252-2 | 1 | IRLR3636TRPBF | C67279
Q5 | SOT-23 | 1 | IRLML2060TRPBF | C75882
Q7 | SOT-23 | 1 | MMBT3904 | MMBT3904
R1 | 0603 | 1 | 270k | RC0603FR-07270KL
R10, R11 | 0603 | 2 | 5k1 | C23186
R12, R13, R14, R15, R19, R22, R23, R24 | 0603 | 8 | 10k | C25804
R16, R17 | 0603 | 2 | 33 | C23140
R18 | 0603 | 1 | 330 | C23138
R2 | 0603 | 1 | 22k | RC0603FR-0722KL
R20, R25 | 0603 | 2 | 100 | C22775
R21, R26, R3 | 0603 | 3 | 100k | C25803
R27 | 0603 | 1 | 470 | C23179
R28 | 0603 | 1 | 47k | C25819
R29 | 0603 | 1 | 47k5 | RC0603FR-0747K5L
R30, R4 | 0603 | 2 | 47k | RC0603FR-0747KL
R31, R37, R5, R6 | 0603 | 4 | 100k | RC0603FR-07100KL
R32 | 0603 | 1 | 15k | RC0603FR-0715KL
R33, R34 | 0603 | 2 | 16k | RC0603FR-0716KL
R35 | 0603 | 1 | 1k13 | ERA3AEB1131V
R36 | 0603 | 1 | 49k9 | RC0603FR-0749K9L
R7 | 0603 | 1 | 22k1 | C25961
R8 | 0603 | 1 | 47k5 | C23061
R9 | 0603 | 1 | 1k | C21190
SW1, SW2, SW3, SW4, SW5, SW6 | SW_GCT_SWT0110 | 6 | ~ | SWT0110-020010SSA
U1 | SOT-23-5 | 1 | TLV1701 | TLV1701AIDBVR
U2 | CP2102_GM_QFN28_5x5_P0.5_EP3.25 | 1 | CP2102-GM | CP2102-GM
U3 | SOT-23-6 | 1 | AKS1201 | C7519
U4 | ESP32-WROOM-32E | 1 | ESP32-WROOM-32E-N4 | ESP32-WROOM-32E-N4
U5 | SOP65P640X120-17N | 1 | L7987L | L7987L

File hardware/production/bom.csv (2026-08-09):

Designator | Footprint | Quantity | Value | LCSC Part #
BZ1 | BUZ-SMD_4P-L8.5-W8.5-P8.50-BR | 1 | MLT-8530 | C94599
C11, C6, C8 | 0805 | 3 | 22u | C45783
C12 | 0603 | 1 | 4u7 | C19666
C13, C14, C18, C19, C3, C9 | 0603 | 6 | 100n | C14663
C15, C17, C2 | 0603 | 3 | 1u | C5199872
C16 | 0805 | 1 | 10u | C15850
C4 | 0603 | 1 | 47p | C1671
C5 | CAP-SMD_BD8.0-L8.3-W8.3-FD | 1 | 100u | C401753
C7 | 1210 | 1 | 10u | C437568
D1 | SOT-23 | 1 | BZX84C15 | C500789
D2 | D_SMB | 1 | SMBJ28A | C96335
D3 | 0805 | 1 | LED_Small | C5569446
D4, D5 | Nexperia_CFP3_SOD-123W | 2 | PMEG6020ER | C98663
D6 | D_SOD-123 | 1 | 1N4148W | C81598
F1 | 1206 | 1 | T3A/63V | C354897
FB1 | 1206 | 1 | HCB3216KF-601T30 | C357023
J1 | JST_XH_B3B-XH-A_1x03_P2.50mm_Vertical | 1 | DC Connector | C144394
J2 | USB_C_Receptacle_HRO_TYPE-C-31-M-12 | 1 | USB_C_Receptacle_USB2.0_16P | C165948
J3 | JST_PH_B4B-PH-SM4-TB_1x04-1MP_P2.00mm_Vertical | 1 | Sensor | C160354
J5 | JST_XH_B2B-XH-A_1x02_P2.50mm_Vertical | 1 | Heater Connector | C158012
J6 | JST_PH_B2B-PH-SM4-TB_1x02-1MP_P2.00mm_Vertical | 1 | Fan Connector | C160352
J7 | JST_GH_BM02B-GHS-TBT_1x02-1MP_P1.25mm_Vertical | 1 | NTC Connector | C161690
L1 | IND-SMD_L7.0-W6.6_ZD0650-100M | 1 | 8u2 | C48031458
Q1 | TO-252-2 | 1 | DMP6180SK3-13 | C93034
Q2, Q3, Q6 | SOT-23 | 3 | MMBT3904 | C94514
Q4 | TO-252-2 | 1 | IRLR3636TRPBF | C67279
Q5 | SOT-23 | 1 | CJ2310 | C75882
R1, R21, R26, R3, R5 | 0603 | 5 | 100k | C25803
R10, R11 | 0603 | 2 | 5k1 | C23186
R12, R13, R14, R15, R19, R22, R23, R24 | 0603 | 8 | 10k | C25804
R16, R17 | 0603 | 2 | 33 | C23140
R18 | 0603 | 1 | 330 | C23138
R20, R25 | 0603 | 2 | 100 | C22775
R27 | 0603 | 1 | 470 | C23179
R28 | 0603 | 1 | 47k | C25819
R6 | 0603 | 1 | 31k6 | C25967
R7 | 0603 | 1 | 22k1 | C25961
R8 | 0603 | 1 | 47k5 | C23061
R9 | 0603 | 1 | 1k | C21190
SW1, SW2, SW3, SW4, SW5, SW6 | SW-SMD_L3.9-W3.0-P4.45 | 6 | ~ | C720477
U1 | AP66200_U-QFN4040-16_EP2.6x2.6mm_P0.65mm | 1 | AP66200 | C6741205
U2 | CP2102N_GQFN28_5x5mm_P0.5mm_EP3.35x3.35mm | 1 | CP2102N-A02-GQFN28R | C964632
U3 | SOT-23-6 | 1 | USBLC6-2SC6 | C7519
U4 | ESP32-WROOM-32E | 1 | ESP32-WROOM-32E-N4 | C701341

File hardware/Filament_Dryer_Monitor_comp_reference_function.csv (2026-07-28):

Reference | Qty | Value | DNP | Exclude from BOM | Exclude from Board | Footprint | Datasheet | Function
L1 | 1 | 8u2 |  |  |  | JLCPCB:IND-SMD_L7.0-W6.6_ZD0650-100M | ZD0650-8R2M | L1
F1 | 1 | T3A/63V |  |  |  | Fuse:Fuse_1812_4532Metric |  | F1
BZ1 | 1 | MLT-8530 |  |  |  | JLCPCB:BUZ-SMD_4P-L8.5-W8.5-P8.50-BR | https://lcsc.com/product-detail/Buzzers_MLT-8530_C94599.html | BUZZER1
C16 | 1 | 10u |  |  |  | Capacitor_SMD:C_0805_2012Metric |  | C_esp1
C12 | 1 | 4u7 |  |  |  | Capacitor_SMD:C_0603_1608Metric |  | C_vdd1
C3,C13,C14,C18,C19 | 5 | 100n |  |  |  | Capacitor_SMD:C_0603_1608Metric |  | Cbst1, C_esp3, C_ntc1, C_reg1, C_vdd2
C1 | 1 |  | DNP |  |  | Capacitor_SMD:C_0603_1608Metric |  | Cen1
C4 | 1 | 47p |  |  |  | Capacitor_SMD:C_0603_1608Metric |  | Cff1
C5 | 1 | 100uF/50V |  |  |  | JLCPCB:CAP-SMD_BD8.0-L8.3-W8.3-FD |  | Cin1
C7 | 1 | 10µF/63V X7R |  |  |  | Capacitor_SMD:C_1210_3225Metric |  | Cin2
C9 | 1 | 100nF / 50V |  |  |  | Capacitor_SMD:C_0603_1608Metric |  | Cin3
C6,C8,C11 | 3 | 22u 25V X5R |  |  |  | Capacitor_SMD:C_0805_2012Metric | 16V X7R | Cmcu1, Cout1, Cout2
C10 | 1 | 470u | DNP |  |  | Capacitor_SMD:CP_Elec_8x10 |  | Cout3
C2,C15,C17 | 3 | 1u |  |  |  | Capacitor_SMD:C_0603_1608Metric | 16V X7R | Cvcc1, C_en1, C_esp2
D6 | 1 | 1N4148W |  |  |  | Diode_SMD:D_SOD-123 | https://www.vishay.com/docs/85748/1n4148w.pdf | D_buz1
D4,D5 | 2 | PMEG6020ER |  |  |  | Diode_SMD:Nexperia_CFP3_SOD-123W |  | D_fan1, D_heat1
D3 | 1 | LED_Small |  |  |  | LED_SMD:LED_0805_2012Metric |  | D_led1
D1 | 1 | BZX84C15 |  |  |  | Package_TO_SOT_SMD:SOT-23 |  | Dz1
FB1 | 1 | HCB3216KF-601T30 |  |  |  | Inductor_SMD:L_1206_3216Metric |  | FB1
J2 | 1 | USB_C_Receptacle_USB2.0_16P |  |  |  | FilamentDryer:USB_C_Receptacle_HRO_TYPE-C-31-M-12 | https://www.usb.org/sites/default/files/documents/usb_type-c.zip | J2
J1 | 1 | DC Connector |  |  |  | Connector_JST:JST_XH_B3B-XH-A_1x03_P2.50mm_Vertical |  | J_dc1
J4 | 1 | Display |  |  |  | FilamentDryer:Oled 1.54 Inch SSD1309 TZT |  | J_display1
J6 | 1 | Fan Connector |  |  |  | FilamentDryer:JST_PH_B2B-PH-SM4-TB_1x02-1MP_P2.00mm_Vertical |  | J_fan2
J5 | 1 | Heater Connector |  |  |  | Connector_JST:JST_XH_B2B-XH-A_1x02_P2.50mm_Vertical |  | J_heat1
J7 | 1 | NTC Connector |  |  |  | Connector_JST:JST_GH_BM02B-GHS-TBT_1x02-1MP_P1.25mm_Vertical |  | J_ntc1
J3 | 1 | Sensor |  |  |  | FilamentDryer:JST_PH_B4B-PH-SM4-TB_1x04-1MP_P2.00mm_Vertical |  | J_sens1
Q1 | 1 | DMP6180SK3-13 |  |  |  | Package_TO_SOT_SMD:TO-252-2 |  | Q1
Q2,Q3,Q6 | 3 | MMBT3904 |  |  |  | Package_TO_SOT_SMD:SOT-23 | https://www.onsemi.com/pdf/datasheet/pzt3904-d.pdf | Q_boot1, Q_buz1, Q_rst1
Q5 | 1 | DMN6140L |  |  |  | Package_TO_SOT_SMD:SOT-23 |  | Q_fan1
Q4 | 1 | IRLR8256 |  |  |  | Package_TO_SOT_SMD:TO-252-2 |  | Q_heat1
R12,R13,R14,R15,R19,R22,R23,R24 | 8 | 10k |  |  |  | Resistor_SMD:R_0603_1608Metric |  | R_btn1-R_btn4, R_en1, R_io0, R_pu_scl1, R_pu_sda1
R27 | 1 | 470 |  |  |  | Resistor_SMD:R_0603_1608Metric |  | R_buz1
R10,R11 | 2 | 5k1 |  |  |  | Resistor_SMD:R_0603_1608Metric |  | R_cc1, R_cc2
R20,R25 | 2 | 100 |  |  |  | Resistor_SMD:R_0603_1608Metric |  | R_g_fan1, R_g_heat1
R18 | 1 | 330 |  |  |  | Resistor_SMD:R_0603_1608Metric |  | R_led1
R9 | 1 | 1k |  |  |  | Resistor_SMD:R_0603_1608Metric |  | R_rst1
R16,R17 | 2 | 33 |  |  |  | Resistor_SMD:R_0603_1608Metric |  | R_s_scl1, R_s_sda1
R8 | 1 | 47k5 |  |  |  | Resistor_SMD:R_0603_1608Metric |  | R_vbus_bot1
R7 | 1 | 22k1 |  |  |  | Resistor_SMD:R_0603_1608Metric |  | R_vbus_top1
R2 | 1 |  | DNP |  |  | Resistor_SMD:R_0603_1608Metric |  | Ren_bot1
R1,R3,R5,R21,R26,R28 | 6 | 100k |  |  |  | Resistor_SMD:R_0603_1608Metric |  | Ren_top1, Rfb_top1, Rg1, R_ntc1, R_pd_fan1, R_pd_heat1
R6 | 1 | 31k6 |  |  |  | Resistor_SMD:R_0603_1608Metric |  | Rfb_bot1
R4 | 1 | 100k | DNP |  |  | Resistor_SMD:R_0603_1608Metric |  | Rpg1
SW1 | 1 | SW_RST |  |  |  | JLCPCB:SW-SMD_L3.9-W3.0-P4.45 |  | SW1
SW2 | 1 | SW_BOOT |  |  |  | JLCPCB:SW-SMD_L3.9-W3.0-P4.45 |  | SW2
SW4 | 1 | Mode |  |  |  | JLCPCB:SW-SMD_L3.9-W3.0-P4.45 |  | SW_m1
SW6 | 1 | Down |  |  |  | JLCPCB:SW-SMD_L3.9-W3.0-P4.45 |  | SW_down1
SW3 | 1 | On/Off |  |  |  | JLCPCB:SW-SMD_L3.9-W3.0-P4.45 |  | SW_onoff1
SW5 | 1 | Up |  |  |  | JLCPCB:SW-SMD_L3.9-W3.0-P4.45 |  | SW_up1
TP1 | 1 | 24V_PROT |  |  |  | TestPoint:TestPoint_Pad_1.5x1.5mm |  | TP1
TP2 | 1 | 3V3_MCU |  |  |  | TestPoint:TestPoint_Pad_1.5x1.5mm |  | TP2
TP3 | 1 | GND |  |  |  | TestPoint:TestPoint_Pad_1.5x1.5mm |  | TP3
TP4 | 1 | EN_ESP |  |  |  | TestPoint:TestPoint_Pad_1.5x1.5mm |  | TP4
TP6 | 1 | ESP_TXD0 |  |  |  | TestPoint:TestPoint_Pad_1.5x1.5mm |  | TP5
TP7 | 1 | ESP_RXD0 |  |  |  | TestPoint:TestPoint_Pad_1.5x1.5mm |  | TP6
TP5 | 1 | IO0 |  |  |  | TestPoint:TestPoint_Pad_1.5x1.5mm |  | TP7
D2 | 1 | SMBJ28A |  |  |  | Diode_SMD:D_SMB |  | TVS1
U4 | 1 | ESP32-WROOM-32E |  |  |  | RF_Module:ESP32-WROOM-32E | https://www.espressif.com/sites/default/files/documentation/esp32-wroom-32e_esp32-wroom-32ue_datasheet_en.pdf | U1
U1 | 1 | AP66200 |  |  |  | Package_DFN_QFN:QFN-16-1EP_4x4mm_P0.65mm_EP2.5x2.5mm |  | U2
U2 | 1 | CP2102N-Axx-xQFN28 |  |  |  | Package_DFN_QFN:QFN-28-1EP_5x5mm_P0.5mm_EP3.35x3.35mm | https://www.silabs.com/documents/public/data-sheets/cp2102n-datasheet.pdf | U3
U3 | 1 | USBLC6-2SC6 |  |  |  | Package_TO_SOT_SMD:SOT-23-6 | https://www.st.com/resource/en/datasheet/usblc6-2.pdf | U4

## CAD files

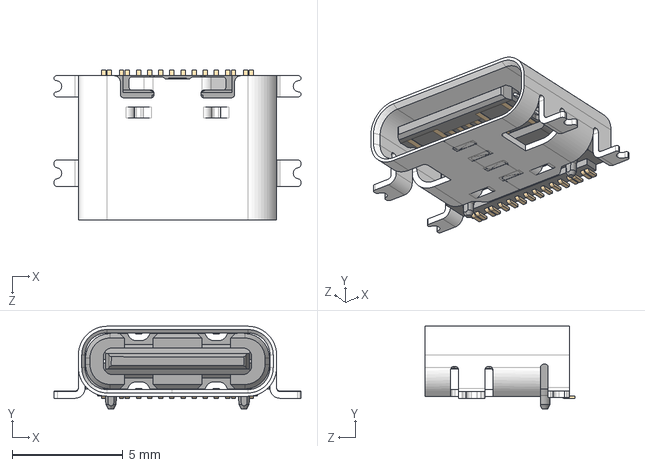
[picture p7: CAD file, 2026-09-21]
hardware/3dmodels/USB4216-03-A.stp
11.1 x 3.73 x 6.75 mm
USB4216 Shell
USB4216 Housing&Terminal

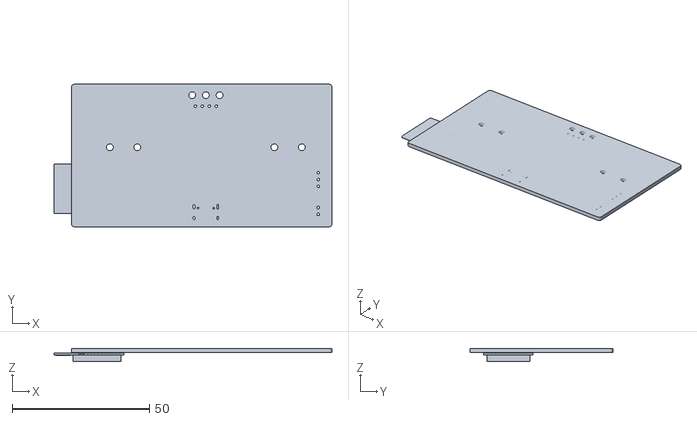
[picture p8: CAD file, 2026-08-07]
hardware/Filament_dryer_pcb.stl
101.4 x 52.0 x 4.70

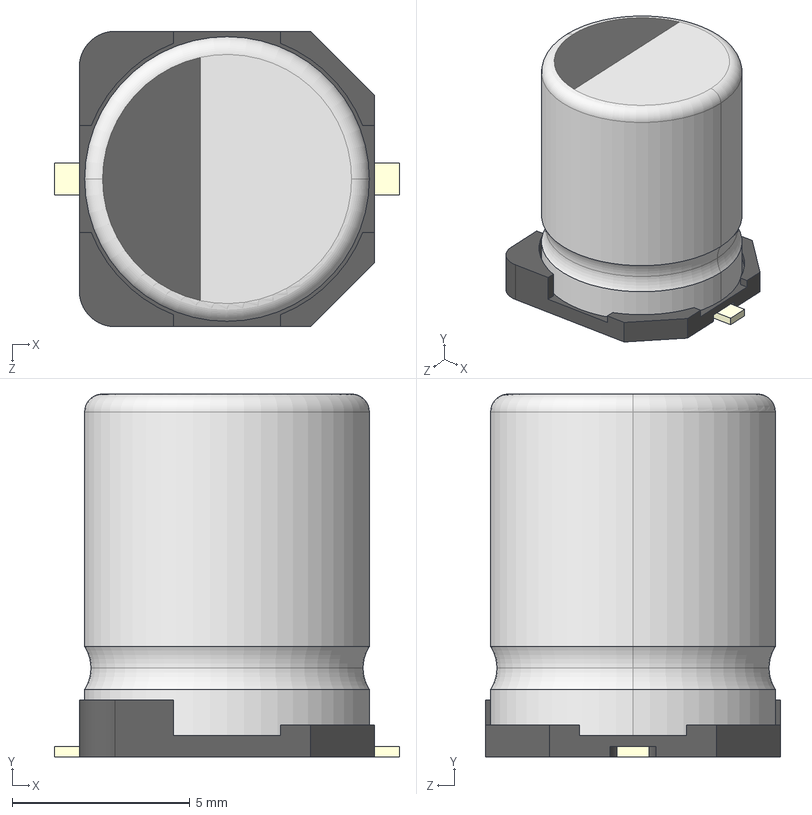
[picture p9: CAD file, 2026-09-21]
hardware/3dmodels/EEEFK1H101P.stp
9.70 x 10.2 x 8.30 mm
標準SIZE CODE F-001
標準SIZE CODE F-002
標準SIZE CODE F-003 x 2

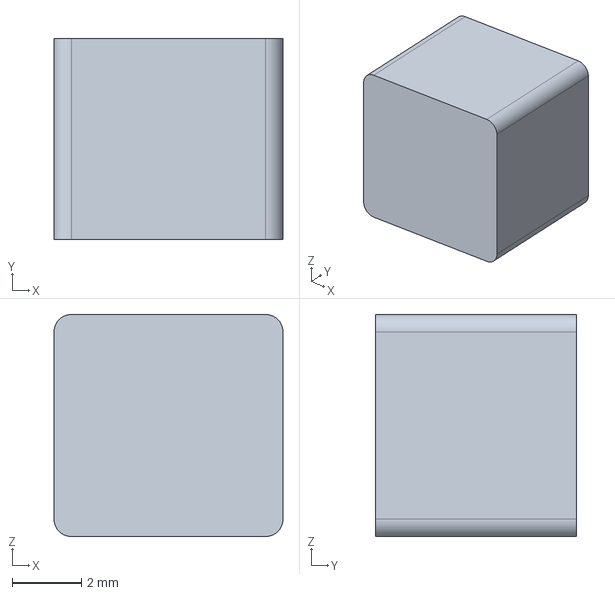
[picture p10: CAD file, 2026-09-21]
hardware/3dmodels/SRN6045-150M.stp
6.60 x 5.80 x 6.40 mm

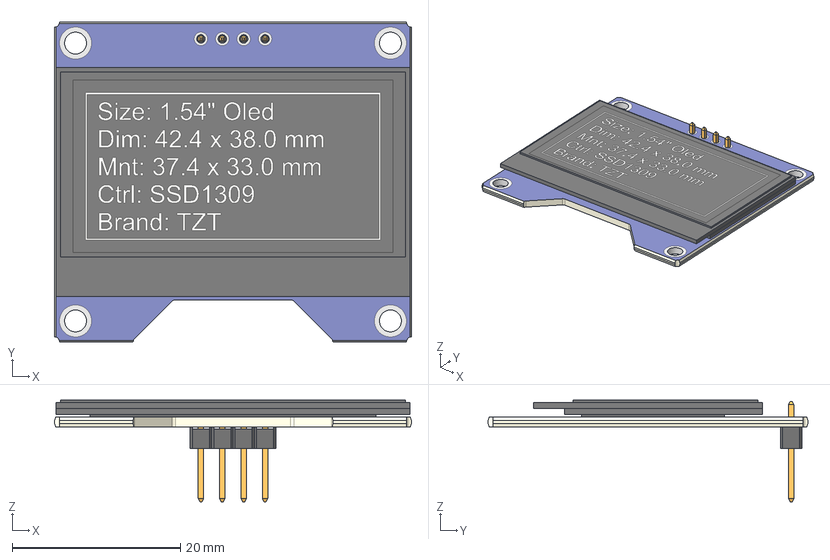
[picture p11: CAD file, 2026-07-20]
hardware/3dmodels/Oled 1.54 Inch SSD1309 TZT.step
42.4 x 38.0 x 12.1 mm
PCB
Adhesive
Display
4-Pin Header - Male - 2.54mm

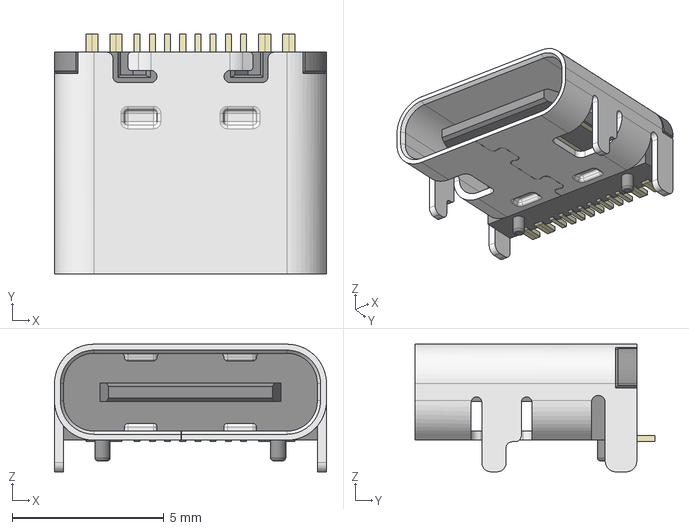
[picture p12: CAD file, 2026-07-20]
hardware/3dmodels/HRO_TYPE-C-31-M-12.step
8.95 x 7.90 x 4.20 mm

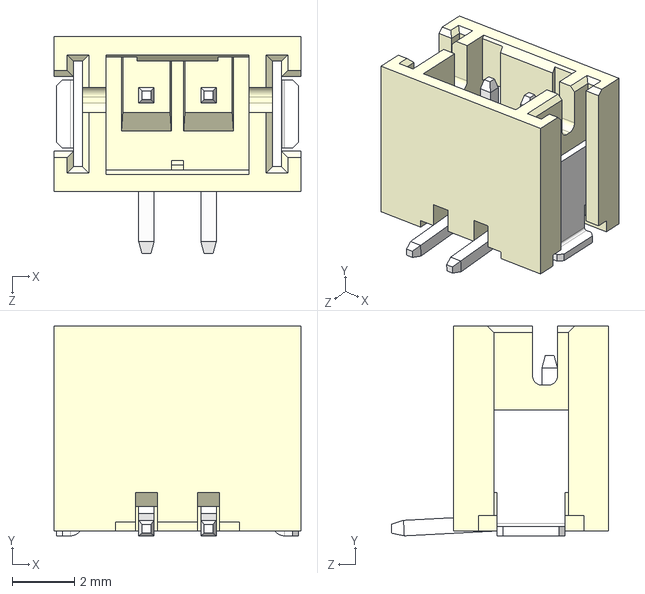
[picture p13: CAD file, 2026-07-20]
hardware/3dmodels/B2B-PH-SM4-TB.STEP
7.95 x 6.75 x 7.00 mm

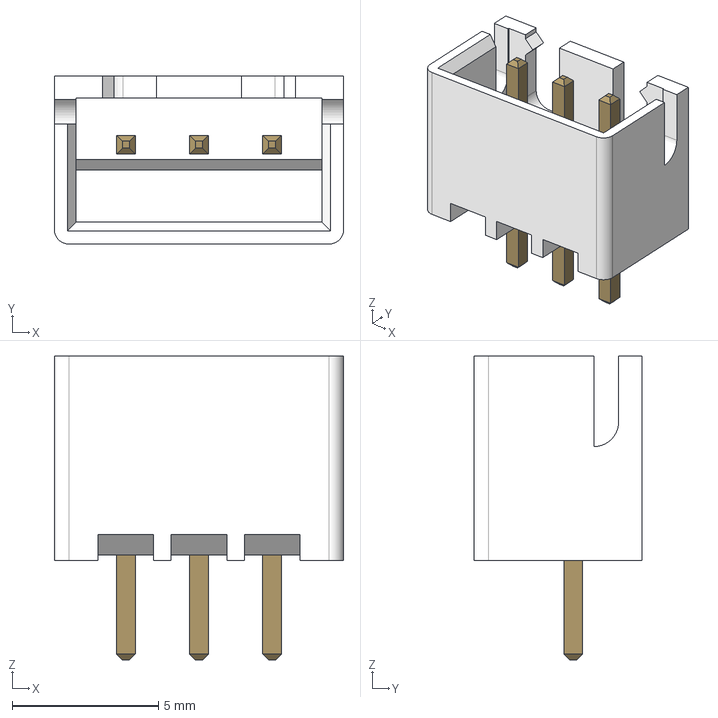
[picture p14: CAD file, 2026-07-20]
hardware/3dmodels/XH_top_entry_3P.step
9.90 x 5.75 x 10.4 mm
Top_entry_base
Pin x 3

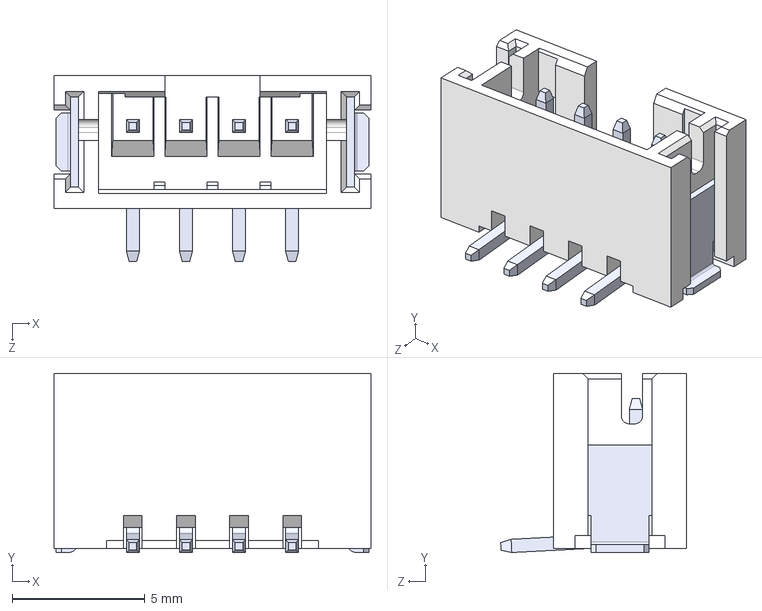
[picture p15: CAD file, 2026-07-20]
hardware/3dmodels/B4B-PH-SM4-TB.STEP
12.0 x 6.75 x 7.00 mm

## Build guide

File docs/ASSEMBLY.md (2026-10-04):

# Assembly and bring-up order

Hand assembly with hot air and a fine-tip iron. This document covers only the steps where
assembly order carries engineering meaning. Ordinary reflow/soldering sequence is not
prescribed here.

## Before assembly — current fabrication and purchasing checkpoint

The current prototype fabrication-source revision is `74a3000` (2026-09-17). Its stored ERC reports 0 errors / 0 warnings; DRC reports 0 active errors / 0 unconnected pads, plus one explicitly excluded U4 silkscreen/board-edge warning. The bare-board Gerbers/drills have been uploaded to JLCPCB and its CAM production file was reviewed, but manufacturing/shipping and physical assembly have not been independently confirmed by this repository. **Do not assemble from an earlier AP66200/CP2102N-era production BOM.** The suffixed `hardware/production/Filament_Dryer_Monitor_bom.csv`, current netlist and live `BOM TME` represent the released design.

As of 2026-09-21 the TME component order has been placed but receipt is not confirmed. C11 (Samsung `CL21A226MAYNNNE`, 22 µF / 25 V X5R / 0805, on `3V3_MCU`) is **unresolved**: TME is checking for its unlocated stock unit. Do not claim C11 has been supplied, omit it from the completed build, or substitute an alternate until the actual part and electrical suitability have been confirmed. An alternative 16 V TDK part was only discussed with TME, **not ordered or approved for the build**. First-article bring-up should wait until the required rail decoupling and the safety-related off-board items are accounted for.

Before population, physically inventory the items marked `In casa` in the sheet (J5 plus 13 resistor rows), compare supplier deliveries with the order confirmation, and identify any missing off-board display/sensor/cutoff/cabling parts. One ordered parts set is sufficient for **one assembled PCB**, even if more bare PCBs are fabricated.

The U5 exposed-pad design remains closed for the planned manual assembly method (see D019). The **R5 assembly sequence below is mandatory** for the first power-up.

## U5 exposed pad — hand-assembly implementation

U5 pad 17 is the 3.2 × 3.2 mm GND exposed pad on B.Cu. The board intentionally does **not** use via-in-pad. Instead, six GND vias (0.60 mm diameter / 0.30 mm drill) sit immediately outside the exposed pad in two rows of three, one above and one below U5. They provide the short thermal/GND path into the internal GND planes while avoiding solder wicking through open vias under the pad.

This arrangement was implemented in commit `c9dc4129` and remains present in the current PCB. For the planned prototype assembly, U5 is fitted by lightly pre-tinning the exposed pad, applying flux, placing the device and heating with hot air. Because no stencil is used for this operation, the full B.Paste definition on pad 17 is not a fabrication blocker for the prototype.

If the assembly process later changes to stencil/reflow or external PCBA, reopen the paste-aperture/via-treatment decision for that process. First-board thermal validation of U5 remains required, but it is a validation item, not unfinished PCB layout.

## R5 — do not fit at first assembly

**Rule: keep R5 unpopulated until the buck has independently produced a verified 3.3 V rail.** For the first article, populate and test functional groups progressively as specified below; do not interpret the historical complete-board wording as a requirement to install every other component before the first power-up.

Reason, in short: U1 (TLV1701) has an open-collector output. If U1 is missing, damaged, or
has one unsoldered pin, R5 pulls its output node up, Q7 conducts, and EN is held low. The
buck never starts and the board shows no 3.3 V — which looks exactly like a dead regulator.

U1 is a hand-soldered SOT-23-5. A single cold joint is a realistic first-power-up outcome,
and without this precaution it sends debugging effort to U5, L1 and the feedback network
while the regulator is actually healthy.

With R5 absent, R30 holds the Q7 base at ground, Q7 stays off, EN is free, and the buck runs
normally without AutoEN protection.

Background: `docs/BUCK_L7987L_DESIGN.md` section 11.3, decision D014.

### Bring-up sequence

1. Populate the complete, electrically necessary input-protection and buck group **except R5**; verify against the actual schematic/netlist that all required bypass, feedback, compensation and output components are fitted. Do not energize an incomplete regulator.
2. Power up. Verify the buck produces 3.3 V.
   - If 3.3 V is absent, inspect the populated supply group and any already-connected load or short; do not assume the regulator IC itself is defective.
     AutoEN is not involved and cannot be the cause.
3. Fit R5. Power up again and verify 3.3 V is still present.
   - If the rail disappears at this step, investigate the AutoEN path (including U1, Q7 and solder joints) and verify the buck independently before replacing parts.
4. Only then proceed to fault-injection testing of AutoEN.

Step 3 is the point of the whole procedure: it separates "the buck does not work" from
"AutoEN is shutting down a working buck".

## Off-board items and first-article inventory

The thermal cutoff (~100–110 °C) is **off-board, in series with HEATER+**, and must not be omitted when wiring the assembly into the enclosure. Its physical procurement/installation and open-circuit behavior must be checked before the heater is enabled.

The **94 PCB-mounted references** in the live `BOM TME` do not include the separate **1.54-inch SSD1309 OLED for J4**, **SHT45 humidity/temperature sensor for J3**, the thermal cutoff, mating JST housings/contacts/cables, heater/fan/NTC wiring or enclosure/mounting parts. Verify exact in-hand availability and pinout/fit rather than assuming that a complete PCB BOM covers the assembled dryer.

For the first board, verify the actual mating J5 connector's polarization and fit, J4 OLED form factor, J3 SHT45 harness, and electrical isolation/current paths before energizing the heater. Do not enable normal heater operation until firmware NTC fault handling and independent thermal cutoff protections have been tested.

## First-article handoff — staged assembly and diagnostic firmware (agreed 2026-09-21)

**Resume here when the bare boards and required components arrive.** The first article will be assembled and checked in functional groups rather than populating the entire PCB before the first electrical test. This changes the *assembly/test plan only*, not the released PCB, schematic, BOM or accepted circuit decisions. The R5 rule above remains mandatory.

Before soldering, inspect the released PCB, schematic, netlist, current firmware and actual delivered parts. Produce a reference-by-reference population matrix for each group, identify accessible measurement points, and check whether leaving later groups unpopulated actually isolates their loads (especially the FB1 path from `3V3_BUCK` to `3V3_MCU`). Do not guess which parts can be omitted from a live regulator or apply power to an incomplete feedback/compensation/bypass network. Define bench supply current limits and measured acceptance criteria before energizing the first article; the table below is a planning outline, not a validated step-by-step test instruction.

| Group | Planned population / verification gate |
|---|---|
| 1 — input and buck | Populate the complete input protection and L7987L power stage, including every electrically necessary support component, **without R5**. With external loads disconnected, inspect for shorts and check regulated 3.3 V and supply behavior using a current-limited bench supply. Verify actual isolation of unpopulated downstream groups before power-up. |
| 2 — rail distribution and AutoEN | Populate the remaining required rail-distribution/AutoEN parts; fit R5 **only after** the initial 3.3 V check, then verify 3.3 V again. Fault-injection and recovery tests require a separately reviewed procedure; do not assume an absent 3.3 V uniquely identifies U1. |
| 3 — ESP32, boot and USB-UART | Populate the complete MCU/boot/programming group. Check supply and USB enumeration, then flash and run the pre-prepared diagnostic firmware over serial before adding later peripherals. |
| 4 — low-power interfaces | Populate and check the sensor/display connectors, buttons, LED, buzzer and NTC interface in suitable groups. Exercise each with diagnostic firmware while fan and heater remain disabled. Confirm the actual off-board modules, wiring and connector pinouts before connection. |
| 5 — output stages and external loads | Populate fan/heater driver groups; check their power-up OFF states and outputs without energizing the heater. Test the fan separately. Heater load testing requires validated NTC calibration/fault handling and the independent off-board thermal cutoff installed and checked; never bypass these gates through a diagnostic command. |

**Firmware timing:** prepare and compile a minimal diagnostic firmware *before assembly*, based on the current GPIO map and actual source. It must default fan and heater OFF, expose boot/serial diagnostics and independently test inputs and low-power outputs. Flash it at group 3 and use it at each subsequent gate. Heater diagnostics must inhibit energization on missing, invalid or faulty NTC readings and must not bypass the independent thermal cutoff. The complete application (OLED UI, drying-cycle control, logging and web UI) follows successful first-article hardware/safety validation; it is not a prerequisite for initial bring-up.

**Current first-article status (2026-10-04):** staged assembly and power-up are in progress. Gate 1 input/buck/rail-link checks have passed at no load, and Gate 3 MCU/USB hardware is populated. MCU 3.3 V, EN/IO0 and manual RESET/BOOT checks pass. USB enumeration is currently blocked by a Windows Code 43 / `USB\\DEVICE_DESCRIPTOR_FAILURE`; cable and host-port changes did not alter the failure, and continuity/power checks through J2/U3/U2 have not yet identified the cause. Diagnostic firmware has therefore not yet been flashed. Load/ripple/thermal/fault validation and all heater-safety gates remain pending. See `docs/FIRST_ARTICLE_TEST_MATRIX.md` and `docs/PROJECT_STATE.md` for measured results.

**Gate 3 USB update (2026-10-04):** after reworking U2 perimeter pins, the CP2102 enumerates successfully on Windows as Silicon Labs CP210x USB to UART Bridge (COM5). The previous device-descriptor failure is resolved. Next bring-up step is UART/ESP32 boot and programming validation.

**First-article auto-program bodge (2026-10-04):** the released board's Q2/Q3 auto-download truth table is reversed. The validated prototype correction is to cross the two collector destinations: Q2 collector -> EN and Q3 collector -> IO0. After this bodge, automatic esptool programming and RTS reset work without manual BOOT/RESET. This is a first-article rework only; D020 records the required source correction for the next hardware revision.

**Gate 3 completion (2026-10-04):** USB/UART programming and runtime serial diagnostics passed on the first article after the validated Q2/Q3 collector-cross bodge. The diagnostic sketch runs and prints periodic `alive` messages at 115200 baud. Gate 4A I2C support is the next staged population group.

**J3 / SHT45 first-article harness status (2026-10-04):** J3 on the PCB is JST-PH 4-way, 2.00 mm pitch (`B4B-PH-SM4-TB`). The external SHT45 currently ends in four loose leads: black=GND, green=SDA, yellow=SCL, red=3V3. It is not yet connected. Terminate those leads into the mating 4-way PH housing so the PCB sees J3-1=GND, J3-2=SDA, J3-3=SCL, J3-4=3V3. Verify the finished harness with continuity/voltage checks before insertion; do not substitute an XH housing, which is a different family/pitch. The user presently has XH parts only; a PH 2.00 mm assortment is being considered but is not yet recorded as purchased. An old README reference to a STEMMA QT cable described the sensor ecosystem, not the actual released PCB mating connector; the fabricated J3 interface is PH.

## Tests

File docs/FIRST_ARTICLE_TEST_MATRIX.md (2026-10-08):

# First-article staged population matrix — working draft

Status: **first-article assembly and staged bring-up in progress**. Active branch `main`; released hardware source checkpoint `74a3000127371ac6c3b3b7197f9036dec5b58eef`. Derived from the stored 2026-09-17 KiCad netlist, current BOM, `docs/ASSEMBLY.md` and source sheets. This is **not yet a solder-by-reference instruction**: the released PCB has now been read successfully through the GitHub contents endpoint and key pad/net locations below are source-verified, but the exhaustive 94-reference population grouping and bench acceptance limits still require completion before assembly.

## Verified net relationships relevant to the staging

- `/Power/3V3_BUCK`: U5, L1, C10, C20, C21, R36 and **FB1**.
- `3V3_MCU`: FB1, **C11**, TP2, U4 (ESP32), U2 (CP2102-GM), J3, J4 and multiple local bypass/passive components. FB1 is the series connection between the buck output and MCU rail: downstream loads are not automatically isolated when FB1 is fitted.
- `24V_PROT`: Q1, U5, U1, TP1 and the 24 V input protection/load connections; TP3 is on GND.
- `/Power/EN`: U5, Q7, C7, R31 and R32. R5 connects `24V_PROT` to the U1 output/R6 node. **R5 stays DNP until the buck is verified** (D014); R5 alone is not a complete isolation switch for all downstream circuitry.
- U5 support nets include `Net-(D7-K)` (D7, L1, U5, C6), `Net-(U5-BOOT)` (C6, U5), `Net-(U5-FB)` (C8, C9, R34, R35, R36, U5), `Net-(U5-FSW)` (R4, U5), `Net-(U5-ILIM)` (R29, U5) and `Net-(U5-SS)` (C4, U5). Do not power a buck with any required support circuit absent.
- MCU UART: U4/U2/TP6/TP7; I2C SDA: U4/R14/R17; SCL: U4/R15/R16. NTC: U4/R28/C19/J7. Fan control: U4/R25; heater control: U4/R20; heater switched node: Q4/D4/J5.

## PCB points now verified from the released board source

All of the following are on **B.Cu** in the released PCB:

- TP1 at approximately (160.000, 108.023), pad 1 = `24V_PROT`.
- TP2 at approximately (160.000, 103.500), pad 1 = `3V3_MCU`.
- TP3 at approximately (137.160, 107.950), pad 1 = `GND`.
- FB1 at approximately (160.171, 84.862): pad 1 = `/Power/3V3_BUCK`, pad 2 = `3V3_MCU`. Leaving FB1 unpopulated therefore provides a deliberate electrical break between the regulator output and the MCU rail.
- C10 at approximately (163.219, 84.862): pad 1 = `/Power/3V3_BUCK`, pad 2 = GND. C10 pad 1 is a direct physical buck-output measurement candidate while FB1 is absent.
- C21 at approximately (185.180, 83.592): pad 1 = `/Power/3V3_BUCK`, pad 2 = GND; it is another direct buck-output node.
- U5 at approximately (174.649, 85.116); pad 1 is `/Power/3V3_BUCK`, pads 2-4 are `24V_PROT`, pads 16-17 are GND.
- R5 at approximately (188.482, 90.958): pad 1 = `24V_PROT`, pad 2 = AutoEN/U1-output path. It remains absent for the initial bring-up.
- J1 at approximately (186.952, 111.993): pad 1 = GND, pad 3 = raw 24 V input; pad 2 is intentionally unconnected.

These coordinates establish connectivity/location from the KiCad source, not probe ergonomics. Confirm physical access on the received board before attaching clips or probes.

## Planned assembly gates

| Gate | Intended population | Verify / hold point |
|---|---|---|
| 0 — inventory and unpowered inspection | No soldering; reconcile actual parts, C11, bare board, off-board TCO, connectors and modules. | Inspect for shorts and manufacturing defects; document instruments and current limit before power-up. |
| 1 — protected input + complete buck | Input connector/protection and **all necessary** U5, L1, D7, C1/C3, feedback/compensation/soft-start/limit and output components; leave **R5 absent**. **Leave FB1 unpopulated at this gate** to isolate `3V3_MCU`; measure the regulator output on a verified direct node such as C10 pad 1 (or C21 pad 1) relative to GND. Exact complete buck reference list still requires exhaustive grouping. | Measure input at TP1 relative to TP3; measure buck output directly at a PCB-accessible node; verify current-limited startup. No downstream module or external load attached. |
| 2 — 3V3 distribution + AutoEN | Complete necessary MCU-rail decoupling (including **C11**) and the AutoEN circuitry; fit R5 **after** verified buck output. After the isolated buck gate passes, populate FB1 together with the required `3V3_MCU` decoupling/load group; downstream rail loads must be accounted for before energizing. | Check TP2 relative to TP3, confirm 3.3 V before/after R5. Plan separate controlled AutoEN recovery/fault test; no arbitrary fault injection. |
| 3 — MCU + USB/UART | U4, U2 and their complete required local bypass, reset/boot, USB-C/ESD and serial-support parts, based on full schematic population map. | Power-up default outputs OFF; USB enumeration, serial, boot and flash diagnostic firmware. |
| 4 — low-power peripherals | I2C connector/pull-ups and SHT45/OLED, buttons, status LED, buzzer and NTC front end, as complete testable subgroups. | Diagnostic serial tests for each fitted interface. Heater and fan disabled. |
| 5 — power outputs | Fan and heater MOSFET/driver/support parts, then connect off-board loads **separately**. | Verify OFF defaults first; test fan. Heater load remains prohibited until valid NTC conversion/fault gates and independently installed/tested series thermal cutoff are verified. |

## Firmware deliverable before components arrive

Prepare/compile a **separate diagnostic build**, after reading current firmware source and actual MCU sheet. At startup set both power outputs to safe OFF, report boot/serial and sensor/NTC/button status, and expose explicit individual low-power tests. Do not expose an unrestricted heater ON command or claim that firmware alone can substitute for the independent thermal cutoff. The normal application firmware is a later milestone.

## Unresolved before using this document at the bench

1. Confirm probe/clip ergonomics on the **received physical PCB** for the source-verified nodes above; source connectivity and coordinates are now mapped, but physical access cannot be proven before receipt.
2. Generate an exhaustive 94-reference population table against the released BOM and current schematic/netlist, including every required local decoupler and all dependencies; distinguish DNP-at-gate from permanently unpopulated.
3. Establish a bench supply current limit, measured voltage/ripple/current/thermal acceptance ranges and abort criteria from device data and completed load inventory. Do not invent these values.
4. Inspect current firmware tree and compile diagnostic build. None of these tasks is marked completed merely by creating this draft.

See `docs/ASSEMBLY.md` and `docs/TODO.md` for the accepted handoff and open gates.

## Reference-by-reference staged population plan

This grouping covers the **94 BOM-mounted references**. Test points TP1-TP7 and board-only pads are not BOM purchase items and remain available as designed. The purpose is fault isolation during manual first-article assembly, not a redesign.

### Gate 1A — raw input and protection

Populate:

`J1, F1, Q1, D1, D2, R3, C5`

Hold:

- Do not populate FB1 or R5.
- Do not connect external heater/fan/sensor/display loads.
- U5 buck group is added only at Gate 1B.

Rationale from source/netlist: J1/F1/Q1 form the raw-to-protected 24 V path; D1/R3 are the Q1 gate network; D2 is the protected-rail TVS and C5 is the protected-rail bulk capacitor. TP1 and TP3 are bare-PCB test pads, not parts to populate. C1 is `Cin_buck1` and belongs with the buck stage; C2 is `C_autoen_vdd1` and belongs with the AutoEN stage.

### Gate 1B — complete isolated L7987L buck

Add:

`U5, L1, D7, C1, C3, C4, C6, C8, C9, C10, C20, C21, R4, R29, R33, R34, R35, R36`

Also populate the EN default network needed with AutoEN disabled:

`C7, Q7, R30, R31, R32`

**Gate 1B population is exactly the 23 references listed above. Do not populate any Gate 2 parts yet. In particular leave unpopulated:** `FB1, R5, U1, R1, R2, R6, C2`.

Reasoning:

- C1 is the local buck input capacitor (`Cin_buck1`) on `24V_PROT`/GND.
- C3 is the U5 VCC bypass on `24V_PROT`/GND.
- C4 = soft-start, R4 = FSW, R29 = ILIM.
- C6/D7/L1 form the bootstrap/switch/output path.
- C8/C9/C20 and R33-R36 implement compensation/feedback/output sensing.
- C10/C21 are directly on `3V3_BUCK`.
- With R5 absent, R30 holds Q7 base low; the documented D014 behavior keeps AutoEN from suppressing the initial buck start.
- FB1 absent isolates `3V3_BUCK` from `3V3_MCU`.

Initial measurement: `3V3_BUCK` at C10 pad 1 or C21 pad 1 relative to TP3/GND. Do not use TP2 yet: TP2 is downstream of FB1 on `3V3_MCU`.

### Gate 2 — AutoEN, then 3V3_MCU distribution

First add the complete AutoEN sensing/supply-decoupling path:

`U1, R1, R2, R6, C2`

Then, **only after the isolated buck has passed**, add `R5` and repeat the buck-start check. This preserves D014.

After AutoEN behavior is confirmed sufficiently for normal rail bring-up, populate the rail link and bulk capacitor:

`C11, FB1, TP2`

At this point TP2 is the intended `3V3_MCU` measurement node. The device-local decouplers `C12, C13, C14, C16, C17, C18, C22` are populated with Gate 3 together with U2/U4; do not energize U2/U4 without their local decoupling fitted.

### Gate 3 — ESP32 + boot/reset + USB/UART programming

Populate:

`U4, U2, U3, J2, Q2, Q3, R7, R8, R9, R10, R11, R12, R13, C12, C13, C14, C15, C16, C17, C18, C22, SW1, SW2`

Test points already present in the PCB design:

`TP4, TP5, TP6, TP7`

Dependencies confirmed by netlist:

- J2/U3/U2 = USB-C data/ESD/USB-UART chain.
- R10/R11 = USB-C CC resistors.
- R7/R8 = CP2102 VBUS sensing/divider path.
- R9 = CP2102 reset pull-up.
- Q2/Q3 + R12/R13 + C15 + SW1/SW2 implement the ESP32 EN/IO0 auto/manual boot network.
- U2 and U4 share `3V3_MCU`; U2/U4 UART is accessible at TP6/TP7.

Gate condition: flash and run the diagnostic firmware before adding the remaining functional I/O groups. Firmware must set fan/heater control pins to safe OFF immediately.

### Gate 4A — I2C sensor/display

Populate:

`J3, R14, R15, R16, R17`; J4 is the actual 1.54-inch SSD1309 OLED module, not a PCB connector, and should be added as an off-board/module load only after the unloaded I2C bus checks pass

R14/R15 are the 3V3_MCU-side I2C pull-ups; R16/R17 are the series connections into the J3/J4 SDA/SCL wiring according to the stored netlist. Connect off-board modules only after their actual pinout/fit is checked.

### Gate 4B — buttons and status LED

Populate:

`SW3, SW4, SW5, SW6, R19, R22, R23, R24, D3, R18`

The four button nets terminate at U4 and have their corresponding 10 kΩ rail resistors. D3/R18 form the status LED path.

### Gate 4C — buzzer

Populate:

`BZ1, Q6, D6, R27, R37`

This is the complete buzzer driver/flyback/control subgroup from the stored netlist. Test independently from the power outputs.

### Gate 4D — NTC input

Populate:

`J7, R28, C19`

This completes the NTC divider/filter input to U4. Use measured/known resistor substitutes as appropriate for diagnostic ADC checks before heater operation; the real heater NTC calibration and fault limits remain a separate firmware/safety task.

### Gate 5A — fan output

Populate:

`J6, Q5, D5, R25, R26`

Verify safe OFF first with no fan connected; then test the external fan separately.

### Gate 5B — heater output

Populate:

`J5, Q4, D4, R20, R21`

Do **not** energize the heater merely because this group is populated. Heater load testing remains gated by validated NTC conversion/fault handling and the independent off-board thermal cutoff in series with HEATER+.

### Coverage check

The staged list above assigns all 94 production-BOM references exactly once:

- Gate 1A: 7
- Gate 1B: 23
- Gate 2: 8
- Gate 3: 23
- Gate 4A: 5 production-BOM refs + J4 (schematic/PCB display footprint, excluded from production BOM/position files)
- Gate 4B: 10
- Gate 4C: 5
- Gate 4D: 3
- Gate 5A: 5
- Gate 5B: 5

Total production-BOM coverage: **94** references, plus **J4** as the intentional non-production-BOM display footprint.

Before using the list physically, perform one final cross-check against the delivered components and received PCB. Population order inside each gate should favor low-profile passives before large/hot-air parts where practical, but electrical completeness at the gate boundary is mandatory.

## Bare-board preflight result — 2026-10-01

Reported passed before soldering: `JACK_24V_RAW`, `24V_PROT`, `3V3_BUCK` and `3V3_MCU` showed no short to GND; FB1 pad 1-to-pad 2 was open with FB1 absent; J1 pad 3-to-TP1 was open with F1/Q1 absent. Proceed to Gate 1A.

## Gate 1A powered result — 2026-10-02

Gate 1A powered test passed on 2026-10-02: supply current decayed to ~0 after capacitor charging at 5 V, 12 V and 24 V; TP1 tracked the applied input voltage; Q1 gate measured 0 V at 5 V, 0 V at 12 V and 9.31 V at 24 V, consistent with D1 clamping Q1 |VGS| to about 14.7 V.

## Gate 1B isolated buck result — 2026-10-03

Initial no-load L7987L bring-up passed with R5 and FB1 unpopulated. C11 was also still unpopulated on the downstream MCU rail.

Measured results:

- 8 V input: TP1 = 8 V, EN = 1.00 V, 3V3_BUCK = ~3.3 V, bench-supply indication ~4 mA.
- 12 V input: TP1 = 12 V, EN = 1.53 V, 3V3_BUCK = ~3.3 V, measured input current ~1.5 mA with DMM in series.
- 24 V input: TP1 = 24 V, EN = 3.08 V, 3V3_BUCK = ~3.3 V, measured input current ~1.5 mA with DMM in series.

Result: isolated buck startup and no-load regulation passed over the tested 8/12/24 V inputs. Load, ripple, transient and thermal validation remain pending.

## AutoEN normal-operation check — 2026-10-03

After fitting R5, normal 24 V operation was rechecked with FB1 and C11 still unpopulated. Measured EN ≈ 3.1 V and 3V3_BUCK ≈ 3.3 V. Result: AutoEN does not inhibit normal buck startup/regulation under this condition.

## 3V3_MCU rail-link check — 2026-10-03

After fitting C11 and FB1, powered at 24 V. Measured input current ≈ 1.8 mA, 3V3_BUCK ≈ 3.3 V, and TP2 / 3V3_MCU ≈ 3.3 V. Result: downstream 3.3 V rail distribution passed at no load.

## Gate 3 MCU + USB/UART bring-up — 2026-10-04

Gate 3 population was reported complete: U2/U3/U4/J2, Q2/Q3, R7-R13, C12-C18, C22 and SW1/SW2 fitted.

Unpowered checks passed before energizing: TP2-to-GND settled at about 36 kΩ; TP4/EN_ESP-to-GND and TP5/IO0-to-GND both settled at about 39.5 kΩ, with capacitor-related transient readings during settling and no stable near-zero short.

Initial 24 V powered check, current limit 50 mA: input current about 8 mA; TP2/3V3_MCU = 3.3 V; TP4/EN_ESP = 3.3 V; TP5/IO0 = 3.3 V. Thermal-camera inspection showed only mild warming around the buck, CP2102 and D2, with no concerning hotspot reported.

Manual reset/boot checks passed: SW1 pulled EN_ESP from 3.3 V to about 2.5 mV while pressed and it returned to 3.3 V when released; SW2 did the same for IO0.

USB enumeration is **not yet passing**. Windows detects a newly attached USB device but reports **Code 43 — Device Descriptor Request Failed** and exposes only `USB\\DEVICE_DESCRIPTOR_FAILURE`, not a CP2102 VID/PID or COM port. The same result persisted after changing both USB cable and host USB port.

Checks completed while isolating the USB fault:

- USB VBUS at R7/J2 side about 4.7 V; R7/R8 divider node about 3.1 V; both sides of R9 about 3.3 V.
- U3 channel continuity: pin 1↔6 and pin 3↔4 continuous; D+ and D− channels not shorted to one another.
- U3→U2 continuity: U3 pin 6→U2 pin 4 and U3 pin 4→U2 pin 5 continuous; crossed checks open.
- J2 duplicated USB-C data pads to U3 were reported continuous for A6/B6→U3 pin 1 and A7/B7→U3 pin 3, with no D+/D− short.
- U3 orientation/supply check passed: pin 5 about 4.7 V and pin 2 about 0 V.
- U2 direct pin checks reported about 3.3 V on VDD, REGIN, VBUS-sense and /RST pins. U2 visual orientation appears consistent with the PCB pin-1 marking; no obvious perimeter solder bridge is visible in the supplied macro image, but hidden QFN joints/exposed-pad quality are not proven by visual inspection.

- Oscilloscope USB check: D+ was observed rising to the Full-Speed idle high level after connection. At 50 ms/div the host was observed forcing D+ low for a reset interval and then releasing it high again, confirming host-side bus reset activity. A subsequent 2 µs/div single-shot trigger on D− (rising, ~1 V) did **not** trigger, so no D− transition was captured on the CP2102 side during the attempted post-reset enumeration. Further scope isolation is required on the connector side of U3 before attributing the fault to U2.

Current Gate 3 state: MCU power/reset/boot behavior passes; USB descriptor enumeration fault remains open. Do not mark USB/UART or diagnostic-firmware flashing complete until this is resolved.

Further USB isolation (2026-10-04): repeating the 2 µs/div single-shot test with a single 10× probe on **U3 pin 3 (D−, connector side)** also produced no trigger. Therefore no D− rising transition has yet been observed either before or after U3. Next diagnostic step is an unpowered resistance/diode check of D− to GND (and comparison with D+) to look for a hard clamp/short before any U2 rework.

Physical inspection follow-up (2026-10-04): U3 pin 3 (D− connector-side channel) was found to move mechanically when touched with a probe. Treat this as a defective/insufficient solder joint and repair U3 before continuing USB electrical diagnosis. Previous static continuity results on this path are no longer sufficient evidence of a reliable joint.

U3 rework result (2026-10-04): all six U3 pins were re-soldered after pin 3 was found mechanically loose. Windows behavior did not change: the board still enumerates only as an unknown USB device with device-descriptor failure. Therefore the loose U3 joint was a real assembly defect but was not sufficient to explain the remaining USB failure. Repeat high-speed D+/D− observation after this rework before changing U2.

Post-U3-rework scope result (2026-10-04): with a single 10× probe on U3 pin 3 (D−, connector side), D− now produces a rising-edge trigger after USB connection. The captured screen was at 100 µs/div, so the apparent ~1 V envelope/decay is not suitable for judging the actual 12 Mbps USB line amplitude or packet shape. This is a real behavioral change from the pre-rework no-trigger result and confirms that the repaired U3 joint affected the D− path, although Windows enumeration still fails. Next step is a faster timebase capture of D−/D+ packet activity.

Post-U3-rework oscilloscope result (2026-10-04): D− on U3 pin 3 (connector side) now shows clear high-speed USB activity. A 2.5 µs/div capture resolves a burst of transitions, whereas the pre-rework D− trigger produced no event. This confirms that the previously loose U3 pin-3 joint affected the USB path at high frequency. Windows descriptor enumeration was still failing immediately after the rework, so the remaining path/device behavior must still be isolated. Next comparison point: U3 pin 4 (CP2102 side) under the same probe/trigger conditions.

Post-rework propagation check (2026-10-04): U3 pin 4 (D−, CP2102 side) shows a waveform reported as practically identical to U3 pin 3 under the same oscilloscope settings. This indicates the observed D− activity is propagating through U3; U3 is therefore no longer the leading suspect for the remaining descriptor failure.

Gate 3 completeness audit (2026-10-04): rechecked the populated USB/CP2102 support against the current MCU schematic/netlist and Silicon Labs CP2102 regulator-bypassed self-powered configuration. No additional production component is missing from Gate 3: VDD has C12 4.7 µF + C13 100 nF; REGIN is tied to 3V3_MCU with C22 1 µF + C14 100 nF; R9 pulls /RST high; R7/R8 provide VBUS sensing; R10/R11 are the USB-C Rd resistors; J2/U3 provide connector/ESD path. CP2102 integrates the Full-Speed transceiver, pull-up/matching and calibrated oscillator, so no external USB termination resistor or crystal is required. A 100 ns/div D− capture after U3 rework shows full-swing high-speed transitions (~3.76 Vpp displayed), confirming bit-level activity but not by itself proving valid descriptor transactions or CP2102 responses.

CP2102 ground check (2026-10-04): with the board unpowered, U2 pin 3 to TP3/GND measured about 0.3 Ω. The CP2102 peripheral GND connection is therefore electrically present; the hidden exposed-pad solder joint remains visually unverifiable but is no longer the leading explanation for the descriptor failure.

Android host cross-check (2026-10-04): with the PCB powered from 24 V and connected to an Android phone as a prospective second USB host, the USB device-info app reported **no device detected**. This is not yet treated as a definitive second-host failure until USB VBUS at J2/R7 is measured while connected to the phone, because lack of OTG/host negotiation would produce the same result.

Android host VBUS check (2026-10-04): with the phone connected, the board-side USB_VBUS node at the J2/U3/R7 side measured about **3.3 V**, not the ~5 V expected from an active USB host. Therefore the Android "no device detected" result is not a valid independent-host enumeration failure; phone OTG/host mode was not established. Do not use this test as evidence against the PCB until a ~5 V host VBUS is confirmed.

USB VBUS backfeed check (2026-10-04): with USB disconnected and the PCB powered only from 24 V, the J2/U3/R7 USB_VBUS node measured about **1 mV**. The board is therefore not backfeeding USB VBUS from 3V3_MCU. The earlier ~3.3 V seen with the Android phone came from the phone/connection state and did not represent a valid ~5 V host VBUS, so that Android enumeration test remains invalid/inconclusive.

Android second-host confirmation (2026-10-04): while the powered board was connected to the Android phone, USB_VBUS measured 5 V at the J2/R7 node, confirming the phone was acting as an active USB host. The Android USB device-info app still reported no device detected. Together with the unchanged Windows Code 43 / device-descriptor failure, this strongly excludes a Windows-specific problem and shifts the leading fault hypothesis to U2 (CP2102) itself or its QFN soldering/hidden exposed-pad joint.

Clarification on U2 GND/EP (2026-10-04): U2 pin 3 and exposed pad 29 are on the same GND net; the PCB exposed-pad copper is tied into GND. Therefore the measured ~0.3 Ω from pin 3 to TP3 confirms the board-side GND network is intact. The only remaining EP uncertainty would be the hidden solder bond between the package exposed pad and the PCB pad itself, not whether the PCB pad has a GND connection. Given the working peripheral GND, this hidden EP joint is not the leading cause of the USB descriptor failure; prioritize perimeter-pin rework/inspection, especially pins 4–9.

USB enumeration resolved (2026-10-04): after reworking the perimeter pins of U2 (CP2102), Windows now enumerates the device successfully as **Silicon Labs CP210x USB to UART Bridge (COM5)**. The previous Code 43 / device-descriptor failure is resolved. Since reworking U3 alone had not fixed enumeration, while U2 perimeter rework did, the fault was most likely a marginal U2 solder joint. The exact pin was not isolated. Gate 3 USB enumeration now passes; proceed to serial/ESP32 communication validation.

Gate 3 UART boot-log check (2026-10-04): with COM5 open at 115200 baud, pressing SW1 RESET produced a valid ESP32 ROM boot log through U4 TXD0 -> U2 RXD -> USB, including `rst:0x10 (RTCWDT_RTC_RESET),boot:0x13 (SPI_FAST_FLASH_BOOT)` and normal flash-load/entry lines. This confirms the ESP32 is running, RESET works, and the ESP32-to-PC UART path is functional. Remaining Gate 3 checks are the reverse UART path and automatic/manual bootloader/programming behavior.
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

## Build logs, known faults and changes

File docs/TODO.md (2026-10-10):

# TODO

Current phase: **first-article hand assembly and staged bring-up** (2026-10-04). Active hardware branch: `main`. Fabrication-source checkpoint: `74a3000127371ac6c3b3b7197f9036dec5b58eef` (2026-09-17, `Production files`). This file tracks remaining work; read `AGENTS.md` and `docs/PROJECT_STATE.md` before changes. Do not silently alter the already submitted fabrication revision.

## Completed / recorded

- [x] Front-panel V1 interaction model specified on 2026-10-08 in `docs/UI_SPEC.md` and accepted as D022: standalone OLED/button operation, safe standby after boot, no automatic cycle resume, temperature/time/fan-AUTO V1 setup, RH displayed/logged but not a standalone completion trigger, fault-priority UI, buzzer event semantics and D3 remaining internal diagnostics.

- [x] Gate 5A real fan load test passed on 2026-10-08: actual 24 V fan started normally; bench input current peaked at ~102 mA and settled at ~89 mA. Static real-load switching path is validated; PWM characterization remains pending.

- [x] Gate 4D analog front end passed on 2026-10-05 with R28=47 kΩ and C19=100 nF: open NTC node ~3.3 V; temporary 100 kΩ to GND gave 2.253 V by DMM; GPIO34 ADC was stable at RAW ~2643-2647 / 2300-2302 mV. The original eSUN NTC has already been empirically characterized and recorded in README.md; J7/real-NTC connection, ADC-path validation, final conversion and fault limits remain pending.

- [x] Gate 4C buzzer first-article test passed on 2026-10-05: BZ1/Q6/D6/R27/R37 populated; GPIO33 ~2.7 kHz tone and a three-note melody both worked. Reduced PWM duty cycle gives a quieter output than the initial ~50% drive; final firmware volume levels remain to be tuned.

- [x] Gate 4B buttons/status-LED first-article test passed on 2026-10-04: SW3/SW4/SW5/SW6 each measure ~3.3 V at rest and ~0 V when pressed. BTN_DOWN initially sat at ~0.91 V because of a poor R24 solder joint; reworking R24 restored the expected level. D3/R18 was then validated with a GPIO26 blink test. D3 is an internal diagnostic LED; firmware semantics are fixed by D021. Gate 4A remains blocked only on the external JST-PH SHT45 harness, so Gate 4C buzzer bring-up may proceed independently.

- [x] Gate 3 MCU/USB group fully populated on 2026-10-04. Unpowered rail/node checks passed; at 24 V with a 50 mA current limit the board drew ~8 mA and TP2/3V3_MCU, EN_ESP and IO0 were all 3.3 V. RESET and BOOT switches each pulled their node to ~2.5 mV while pressed. No concerning hotspot was seen on the thermal camera.
- [ ] Resolve Gate 3 USB enumeration failure before flashing diagnostic firmware: Windows reports Code 43 / `USB\\DEVICE_DESCRIPTOR_FAILURE`, unchanged with a different USB cable and host port. VBUS, divider/reset levels, U3 orientation/power, and D+/D− continuity from J2 through U3 to U2 have passed; inspect/verify remaining CP2102/QFN and signal-integrity possibilities before rework.

- [x] Gate 1A powered test passed on 2026-10-02: supply current decayed to ~0 after capacitor charging at 5 V, 12 V and 24 V; TP1 tracked the applied input voltage; Q1 gate measured 0 V at 5 V, 0 V at 12 V and 9.31 V at 24 V, consistent with D1 clamping Q1 |VGS| to about 14.7 V.

- [x] Bare-board rail/isolation preflight reported passed on 2026-10-01 before soldering: no short to GND on raw 24 V, protected 24 V, buck 3.3 V or MCU 3.3 V; FB1 pads isolated; J1 raw input isolated from TP1 with F1/Q1 absent.

- [x] Bare PCBs and component shipment reported received on 2026-10-01; physical inspection and package/quantity reconciliation are still pending and must not be treated as completed.

- [x] L7987L + AutoEN design basis, USB routing, two solid inner GND planes and U5's six peripheral thermal/GND vias accepted in `docs/DECISIONS.md`.
- [x] Updated schematic, 2026-09-17 netlist (correct USB-C D+/D− mapping), ERC (0 errors/0 warnings) and DRC (0 active errors/0 unconnected pads; one intentionally excluded U4 silkscreen-to-board-edge warning) are stored on the active branch.
- [x] Current production-source checkpoint contains `hardware/production/Filament_Dryer_Monitor_bom.csv` and `Filament_Dryer_Monitor_positions.csv`; unsuffixed legacy `bom.csv`/`positions.csv` must not be used.
- [x] Bare-PCB Gerbers/drills uploaded to JLCPCB; a production/CAM package was received and reviewed in the order discussion. Confirm actual manufacturing/shipping status from the supplier; it is not tracked here.
- [x] Live `BOM TME` checked against 94 PCB-mounted references and the current released BOM/netlist (2026-09-19); `TME_IMPORT` excludes in-house references.
- [x] TME order placed 2026-09-20 for the supplier-designated items for one assembled PCB. Original confirmation recorded C11 as in stock.

## Immediate: supplier and component availability

- [ ] **C11 — await TME's definitive warehouse answer.** Ordered Samsung `CL21A226MAYNNNE`, 22 µF / 25 V X5R / 0805, is currently unlocated in their stock. The later week 48/2026 estimate refers to C11 only. **No cancellation or replacement has been approved.**
- [ ] Ask/obtain explicit confirmation that other available TME items will ship without waiting for C11 and without extra fees; the supplier's latest message did not answer that question.
- [ ] If C11 cannot be found, settle shipment/cost/refund with TME before agreeing to any replacement or full-order cancellation. Candidate *only*: TDK `C2012X5R1C226M125AC` (TME `C2012X5R1C226MAC`), 22 µF / 16 V X5R / 0805. Verify exact part and effective capacitance/DC-bias before assembly; do not edit KiCad/BOM solely because it was discussed.
- [ ] On delivery, audit **actual shipped quantities/MPNs and packaging** against order confirmation, the live `BOM TME` and `hardware/production/Filament_Dryer_Monitor_bom.csv`. Supplier-imposed minimum packs may differ from the per-PCB need.
- [ ] Physically verify in-house stocks of J5 and the 13 resistor BOM rows (33 component refs marked `In casa`). In-house label is a planning declaration, **not** a verified physical inventory.
- [ ] Check the separate **off-board** assembly inventory: 1.54-inch SSD1309 OLED module for J4 and its physical fit/pinout, SHT45 sensor and J3 harness, independent heater thermal cutoff (TCO) in the HEATER+ wire, mating JST housings/contacts/leads for J1/J3/J6/J7 where needed, heater/fan/NTC wiring, mounting hardware and actual enclosure clearances. These are **not** covered by the 94-reference PCB BOM. Do not mark them ordered/in-house without evidence.

## Incoming bare PCB and assembly

- [ ] Confirm JLCPCB CAM approval/production status and actual shipment or receipt. Archive the final board-order stackup/production confirmation if useful; the uploaded Gerber/CAM ZIP is not maintained as a repository source file.
- [ ] Inspect incoming PCBs: 91 × 52 mm profile, board thickness, rounded corners, solder mask, plated holes, USB-C/JST footprints, component alignment and 4-layer continuity. Inspect U2's exposed pad and any open plated holes for hand-soldering suitability.
- [ ] Check physical fit/polarization of in-house J5 HALJIA, J4 OLED, J1/J3/J6/J7 mating connectors and BZ1 footprint.
- [ ] **Before assembly**, inspect the actual released PCB/netlist and current firmware, define a reference-by-reference staged population matrix, accessible test points, current limits and pass/fail criteria; prepare and compile a minimal safe-OFF serial diagnostic firmware. See the staged handoff in `docs/ASSEMBLY.md`.
- [ ] Hand assemble and test the first article **by functional groups**, preserving complete buck support circuitry and keeping **R5 unpopulated until initial 3.3 V is verified**. Flash the diagnostic firmware once ESP32/USB is populated and use it at later test gates. Do not omit C11 from the completed functional prototype merely to bypass the supply issue.
- [ ] First-article bring-up: check input protection/fuse, the 3.3 V rails, USB/UART enumeration and boot, I2C SHT45/OLED, buttons, fan/heat MOSFET defaults, buzzer and NTC input before enabling heating.
- [ ] Power/thermal tests: 3.3 V load steps, LX ringing and switch-loop stress, U5/D7/L1/capacitor temperatures, current-limit/foldback and AutoEN shutdown/restart.
- [ ] Install and verify the independent off-board heater TCO. Complete NTC characterization-to-firmware calibration and heater safety gates before normal closed-loop heating.

## Engineering items to verify on the first article / before any later revision

The 2026-09-17 reports replace the obsolete 2026-09-16 release checklist. The PCB has already been submitted for fabrication; **do not silently reclassify these follow-up checks as reasons to alter that released design**.

- [ ] Compare actual JLCPCB stackup/order details with the nominal KiCad USB reference geometry (B.Cu/In2.Cu, 0.20 mm width / 0.25 mm gap, 90 Ω design target). USB functionality needs real-board validation; a CAM comparison alone does not prove impedance.
- [ ] Verify U4 antenna-edge and keepout behavior, U2 pad/USB-C solderability, buck current-loop and quiet-feedback behavior, component-edge clearances, high-current heater/fan routing and all mating/assembly constraints during initial hardware tests.
- [ ] The one excluded U4 B.Silkscreen/edge warning remains documented, not magically fixed. If manufacturing or assembly reveals problems, record evidence and open a **new hardware revision** under `AGENTS.md` and `docs/DECISIONS.md`.
- [ ] Review GitHub CI branch triggers before expecting automatic ERC on future feature-branch PCB changes; for any actual future schematic/PCB revision, generate fresh netlist/ERC/DRC and all fabrication exports from the same revision.

- [x] First-board no-load power bring-up through 3V3_MCU rail (24 V in; ~1.8 mA; 3V3_BUCK and TP2 ~3.3 V). Load/ripple/thermal validation still pending.

- [ ] Gate 3 USB fault: Android second-host test confirmed with 5 V VBUS from the phone, but no device was detected. Windows-specific causes are now unlikely; inspect/reflow U2 CP2102 before replacement or design changes.

- [x] Validate ESP32-to-PC UART path: ROM boot log is readable on COM5 at 115200 after SW1 RESET.
- [ ] Validate PC-to-ESP32 UART path and bootloader/programming, including automatic DTR/RTS reset/BOOT behavior.

- [ ] Automatic upload currently fails at `Connecting...` with esptool `Invalid head of packet (0x65)`; test manual BOOT/RESET download mode next to separate UART RX from DTR/RTS auto-program behavior.

- [x] Manual BOOT/RESET reaches ESP32 ROM downloader and esptool reads chip type/revision/crystal/MAC, proving bidirectional UART.
- [ ] Resolve failure at `Uploading stub flasher...` (`Invalid head of packet (0x65)`): first verify bench current limit/3V3 stability, then test no-stub or alternate esptool version if power is clean.

- [x] Resolve stub-stage upload failure: raising the 24 V bench current limit from 50 mA to 100 mA allowed full esptool write/verify to complete successfully in manual download mode.
- [ ] Repeat upload at 100 mA without touching BOOT/RESET to validate DTR/RTS automatic programming entry.

- [ ] Auto-program remains open: at 100 mA, no-button upload gives `No serial data received`; manual BOOT/RESET upload succeeds. Scope TP4/EN_ESP and TP5/IO0 during automatic connect to identify the DTR/RTS/Q2/Q3 failure.

- [ ] Auto-program hardware defect identified: current Q2/Q3 DTR/RTS cross-coupled network swaps the intended EN/IO0 truth-table behavior versus Espressif reference. Agree and implement a first-article bodge, then open a deliberate schematic/PCB revision; manual BOOT/RESET programming remains usable meanwhile.

- [x] Validate Gate 3 automatic programming on the first article: crossing the Q2/Q3 collector destinations (Q2 collector -> EN, Q3 collector -> IO0) restores no-button esptool upload and automatic RTS reset at a 100 mA bench limit.
- [ ] Open Serial Monitor at 115200 and confirm the newly flashed Gate 3 diagnostic sketch runs and prints its expected messages.
- [ ] Apply D020 in the next schematic/PCB revision: correct the Q2/Q3 auto-program output mapping in source, then regenerate netlist/ERC/DRC/production outputs.

- [x] Close Gate 3 MCU/USB/UART bring-up: automatic programming works after the validated Q2/Q3 collector-cross bodge, and the flashed diagnostic sketch runs correctly at 115200 baud.
- [ ] Gate 4A: populate and test J3 plus R14, R15, R16 and R17; verify the unloaded I2C bus first. J4 is the actual 1.54-inch SSD1309 OLED module (not a connector) and should be connected/tested separately after the bus checks, like the external SHT45 load.

- [x] Gate 4A initial population: J3 and R14-R17 installed; J4 OLED and SHT45 still disconnected.
- [ ] Verify unloaded J3 power/SDA/SCL continuity and powered idle levels before attaching I2C modules.

- [x] Verify unloaded J3 power/SDA/SCL continuity and powered idle levels before attaching I2C modules.
- [x] Verify the actual SHT45 board/harness pinout and JST-PH orientation, then connect and run an I2C/SHT45 diagnostic before adding the OLED. Passed 2026-10-07: sensor supply ~3.3 V, device detected at `0x44`, stable valid temperature/RH readings.

- [x] Obtain/prepare the J3 mating harness: JST-PH 2.00 mm, 4-way housing/contacts or equivalent pre-crimped PH lead set. Kit received and 4-way SHT45 harness assembled by 2026-10-07.
- [x] Before plugging the SHT45 into J3, verify the completed PH harness pin-for-pin against the PCB: J3-1=GND/black, J3-2=SDA/green, J3-3=SCL/yellow, J3-4=3V3/red. Powered diagnostic passed 2026-10-07.

- [x] Connect and test the actual J4 1.54-inch SSD1309 OLED on the validated I2C bus. Passed 2026-10-08 at `0x3C`; U8g2 graphical frame/text rendering confirmed with SHT45 simultaneously present at `0x44`. Gate 4A closed.

- [x] Gate 5A PWM characterization completed for the current fan at 25 kHz: 25% was the first tested duty that started from rest (20% did not); 15% was the lowest tested duty that sustained rotation (10% did not). Earlier current points: 50% ~49 mA, 75% ~72 mA, 100% ~89 mA. Final firmware should retain margin above these observed limits and may use a brief full-duty startup boost.

- [ ] J7 connector mismatch confirmed 2026-10-08: released JST-GH BM02B-GHS-TBT does not mate with the original eSUN NTC plug. First-article plan: keep J7 installed, validate a sacrificial GH crimp, then cut the incompatible NTC plug and reterminate the original ~30 AWG NTC leads into a GH 2-position housing. PEBA micro-crimping kit/tool for GH 1.25 mm purchased 2026-10-08; expected Saturday 2026-10-10. Do not cut the NTC leads until the sample crimp passes. Revisit J7 connector choice in the next deliberate hardware revision.

- [x] Gate 5B unloaded switching path passed 2026-10-08: Q4/D4/R20/R21 installed, J5 left unpopulated, safe-OFF gate 0 V, temporary 100 kΩ pull-up gave 24 V at HEATER_SW when OFF, GPIO19 HIGH gave 3.3 V at Q4 gate and ~1 mV at HEATER_SW. Real heater remains blocked pending NTC/J7 validation, firmware safety handling and TCO.

## Application firmware / front-panel UI

- [ ] Flash and visually validate the new Slewform root-growth boot animation on the real SSD1309: continuous growth, faithful complete emblem, **separate** wordmark appearing at 2.1 s, no audio before that transition, chime synchronized with wordmark, STANDBY at 3.5 s. Original SVG remains authoritative.

- [ ] Validate real fan application control on the first article: with the actual fan connected, start a DRYING test cycle and confirm ~1 s at 100% followed by steady 40% at 25 kHz; confirm long ON/OFF stop and cycle completion both turn the fan fully OFF. Keep the heater disconnected/locked and use an adequate bench current limit.
- [ ] Validate Preferences/NVS persistence across reset/power cycle: change cycle time/temperature UI values and buzzer settings, exit with M-long or start a cycle, reset, and confirm values return; confirm no active cycle auto-resumes.
- [ ] Validate SETTINGS UI: from STANDBY hold M, test buzzer OFF/LOW/MED/HIGH preview and KEY CLICK ON/OFF, then hold M to save/back.

- [ ] Verify on first article that the cleaned-up layout is restored and M-long exits SETUP. Contextual button hints were rejected because they competed with the 128×64 screen content.

- [ ] Reflash after first live UI corrections and verify: Slewform splash now remains visible 3.5 s, pre-logo horizontal/random lines are eliminated or reduced to an unavoidable power-up transient, all temperature fields show `°C`, and heater/fan pins remain LOW.

- [x] Split cycle, fan and safety responsibilities into `CycleController`, `FanController` and `SafetyController`; heater remains hard-locked OFF. Logging and web-interface modules remain future work.
- [x] Implement and live-test debounced active-low button handling with short press, ~1.5 s long press, UP/DOWN autorepeat and wake-consume behavior. First-article interaction test passed 2026-10-08.
- [ ] Complete the D022 state model. BOOT -> STANDBY -> SETUP -> DRYING-demo -> COMPLETE is implemented in `030cb5c` with no auto-resume; real FAULT entry/reset remains pending the safety controller.
- [ ] Complete SSD1309 pages from `docs/UI_SPEC.md`. Slewform boot splash, standby, setup, drying main, technical/system, complete and generic fault screens are implemented in `030cb5c`; final diagnostics and safety-specific fault content remain.
- [ ] Live-test the expanded buzzer manager: persisted OFF/LOW/MED/HIGH levels, optional key click, warning pattern and repeating fault pattern. Code is implemented; acoustic tuning and real safety-fault triggering remain to be validated.
- [x] Implement D021 diagnostic LED patterns in the application firmware (`030cb5c`).
- [ ] Decide and validate target-temperature range/step, cycle-duration range/step, defaults and persistence only after heater/NTC/safety validation supports safe values.
- [ ] Define final fan AUTO policy using the measured first-article fan thresholds with adequate startup/run margin; decide whether a post-cycle cooldown state is required.
- [ ] Keep material profiles and humidity/trend-based automatic completion deferred until their values/algorithm are deliberately designed and validated.

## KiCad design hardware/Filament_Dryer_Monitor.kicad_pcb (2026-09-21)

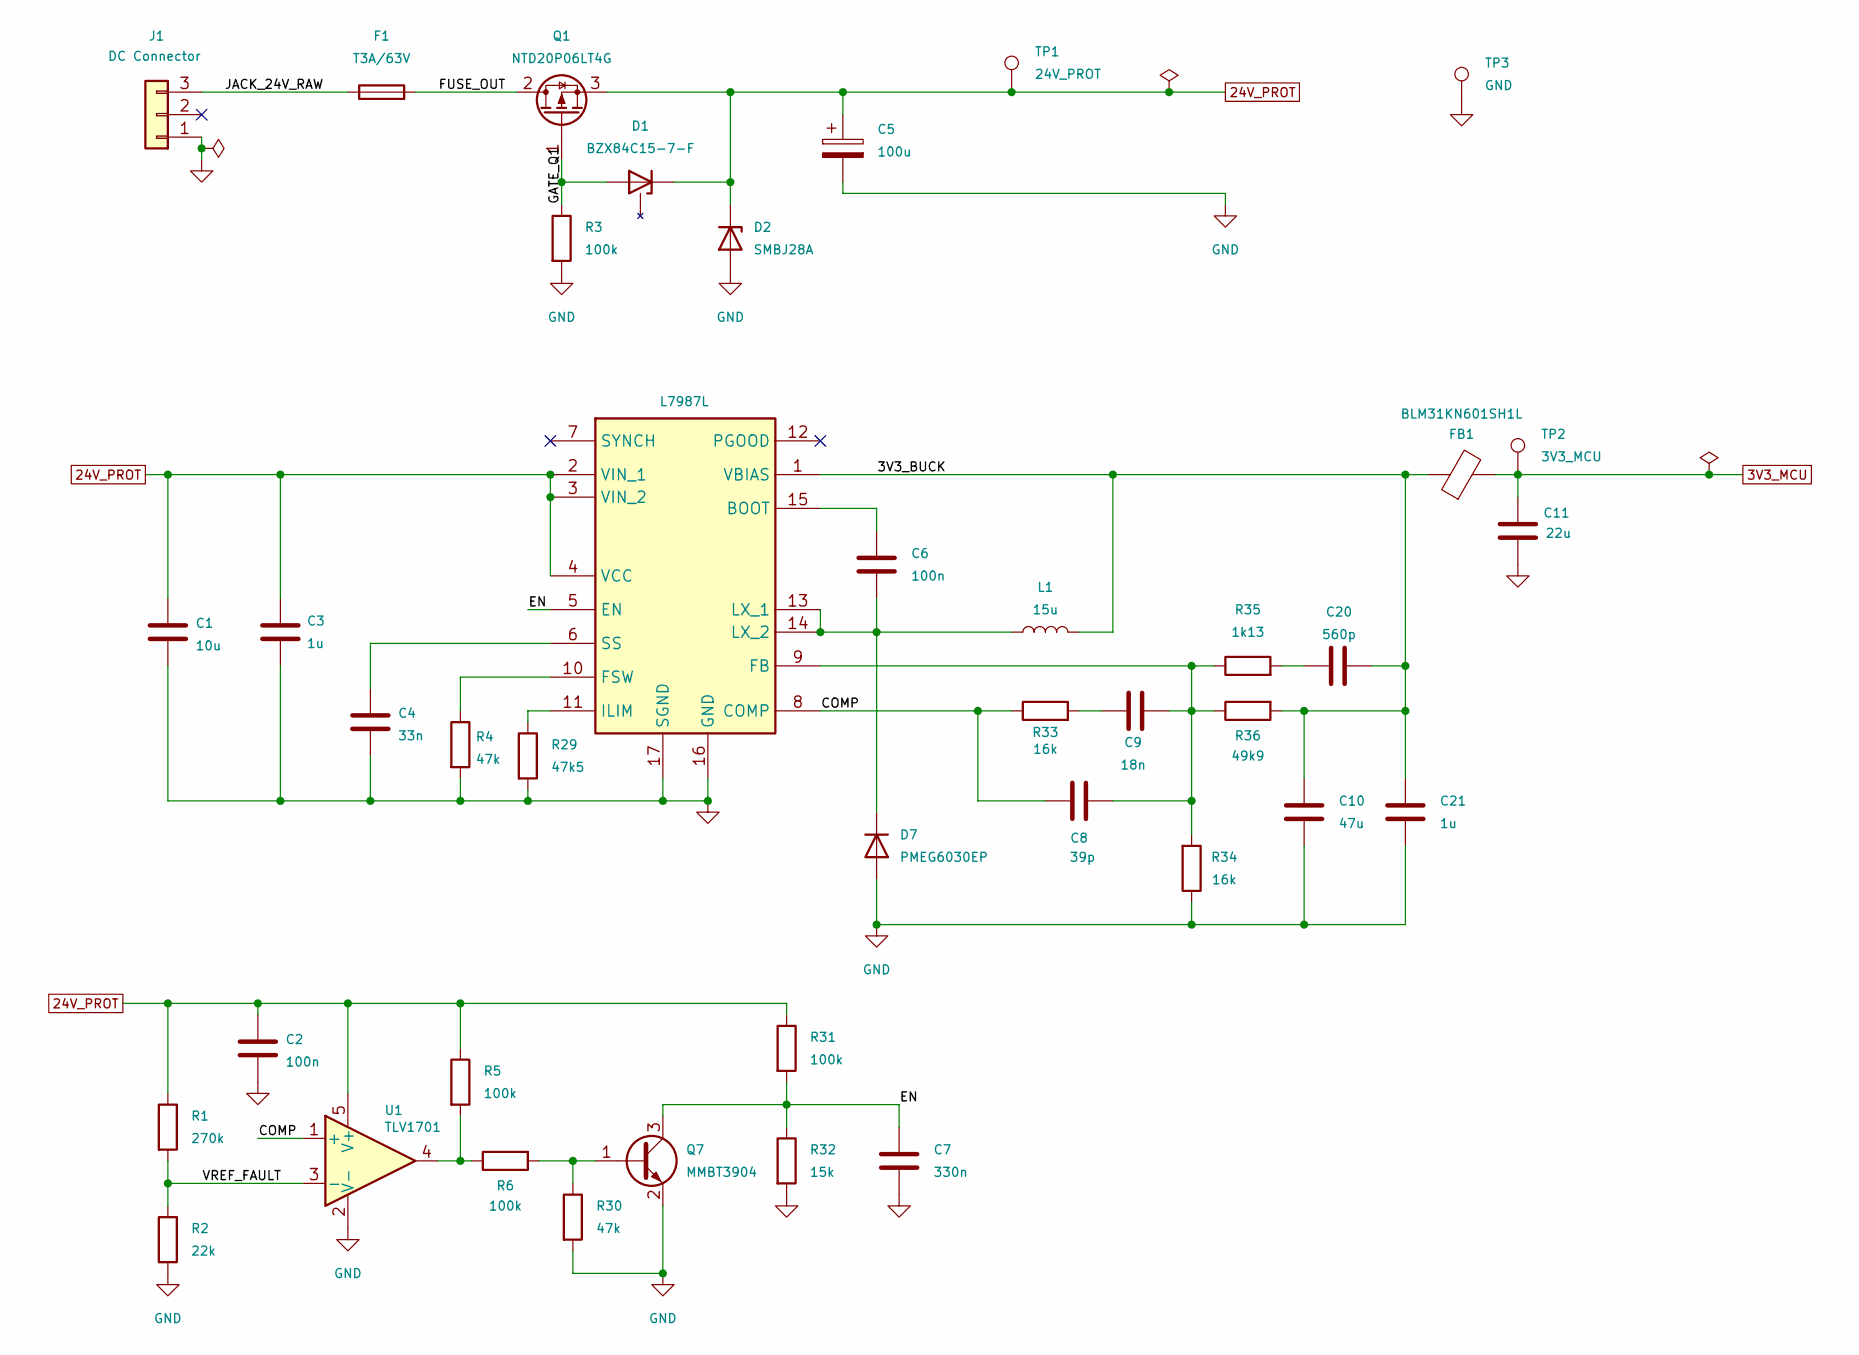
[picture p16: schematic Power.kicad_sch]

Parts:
C1: 10u; C_1210_3225Metric; Tolerance 10%; Voltage 100V; MPN GRM32EC72A106KE05L
C2, C6: 100n; C_0603_1608Metric; Tolerance 10%; Voltage 50V; MPN CC0603KRX7R9BB104
C3: 1u; C_0805_2012Metric; Tolerance 10%; Voltage 100V; MPN GRJ21BC72A105KE11L
C4: 33n; C_0603_1608Metric; Tolerance 10%; Voltage 50V; MPN GCM188R71H333KA55D
C5: 100u; CP_Panasonic_F_8x10.2; Tolerance 20%; Voltage 50V; MPN EEEFK1H101P
C7: 330n; C_0805_2012Metric; Tolerance 10%; Voltage 50V; MPN GRM219R71H334KA88D
C8: 39p; C_0603_1608Metric; Tolerance 5%; Voltage 50V; MPN C0603C390J5GACTU
C9: 18n; C_0805_2012Metric; Tolerance 5%; Voltage 50V; MPN GRM21B5C1H183JA01L
C10: 47u; C_1210_3225Metric; Tolerance 10%; Voltage 10V; MPN LMK325B7476KM-PR
C11: 22u; C_0805_2012Metric; Tolerance 20%; Voltage 25V; MPN CL21A226MAYNNNE
C20: 560p; C_0603_1608Metric; Tolerance 5%; Voltage 50V; MPN 06035A561JAT2A
C21: 1u; C_0603_1608Metric; Tolerance 10%; Voltage 25V; MPN GCM188R71E105KA64J
D1: BZX84C15-7-F; SOT-23; MPN BZX84C15-7-F
D2: SMBJ28A; D_SMB; MPN SMBJ28A
D7: PMEG6030EP; D_SOD-128; MPN PMEG6030EP.115
F1: T3A/63V; Fuse_1206_3216Metric_Pad1.42x1.75mm_HandSolder; MPN 0685T3000-01
FB1: BLM31KN601SH1L; L_1206_3216Metric; MPN BLM31KN601SH1L
J1: DC Connector; JST_XH_B3B-XH-A_1x03_P2.50mm_Vertical; MPN B3B-XH-A (LF)(SN)
L1: 15u; L_Bourns_SRN6045; MPN SRN6045-150M
Q1: NTD20P06LT4G; TO-252-2; MPN NTD20P06LT4G
Q7: MMBT3904; SOT-23; MPN MMBT3904
R1: 270k; R_0603_1608Metric; Tolerance 1%; Voltage 75V; MPN RC0603FR-07270KL
R2: 22k; R_0603_1608Metric; Tolerance 1%; Voltage 75V; MPN RC0603FR-0722KL
R3, R5, R6, R31: 100k; R_0603_1608Metric; Tolerance 1%; Voltage 75V; MPN RC0603FR-07100KL
R4, R30: 47k; R_0603_1608Metric; Tolerance 1%; Voltage 75V; MPN RC0603FR-0747KL
R29: 47k5; R_0603_1608Metric; Tolerance 1%; Voltage 75V; MPN RC0603FR-0747K5L
R32: 15k; R_0603_1608Metric; Tolerance 1%; Voltage 75V; MPN RC0603FR-0715KL
R33, R34: 16k; R_0603_1608Metric; Tolerance 1%; Voltage 75V; MPN RC0603FR-0716KL
R35: 1k13; R_0603_1608Metric; Tolerance 0.1%; Voltage 75V; MPN ERA3AEB1131V
R36: 49k9; R_0603_1608Metric; Tolerance 1%; Voltage 75V; MPN RC0603FR-0749K9L
TP1: 24V_PROT; TestPoint_Pad_1.5x1.5mm
TP2: 3V3_MCU; TestPoint_Pad_1.5x1.5mm
TP3: GND; TestPoint_Pad_1.5x1.5mm
U1: TLV1701; SOT-23-5; MPN TLV1701AIDBVR
U5: L7987L; SOP65P640X120-17N; MPN L7987L

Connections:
3V3_MCU: C11.1, FB1.2, TP2.1 (1_1); also elsewhere on the board
24V_PROT: C1.1, C2.1, C3.1, C5.1, D1.3 (K), D2.1 (K), Q1.3 (S), R1.1, R5.1, R31.1, TP1.1 (1_1), U1.5 (V+), U5.2 (VIN_1), U5.3 (VIN_2), U5.4 (VCC); also elsewhere on the board
/Power/3V3_BUCK: C10.1, C20.2, C21.1, FB1.1, L1.2, R36.2, U5.1 (VBIAS)
/Power/COMP: C8.1, R33.1, U1.1 (+), U5.8 (COMP)
/Power/EN: C7.1, Q7.3 (C), R31.2, R32.1, U5.5 (EN)
/Power/FUSE_OUT: F1.2, Q1.2 (D)
/Power/GATE_Q1: D1.1 (A), Q1.1 (G), R3.1
/Power/JACK_24V_RAW: F1.1, J1.3
/Power/VREF_FAULT: R1.2, R2.1, U1.3 (-)
GND: C1.2, C2.2, C3.2, C4.2, C5.2, C7.2, C10.2, C11.2, C21.2, D2.2 (A), D7.2 (A), J1.1, Q7.2 (E), R2.2, R3.2, R4.2, R29.2, R30.2, R32.2, R34.1, TP3.1 (1_1), U1.2 (V-), U5.16 (GND), U5.17 (SGND); also elsewhere on the board
unnamed: C9.1, R33.2
unnamed: C20.1, R35.2
unnamed: C6.2, D7.1 (K), L1.1, U5.13 (LX_1), U5.14 (LX_2)
unnamed: Q7.1 (B), R6.2, R30.1
unnamed: R5.2, R6.1, U1.4
unnamed: C6.1, U5.15 (BOOT)
unnamed: C8.2, C9.2, R34.2, R35.1, R36.1, U5.9 (FB)
unnamed: R4.1, U5.10 (FSW)
unnamed: R29.1, U5.11 (ILIM)
unnamed: C4.1, U5.6 (SS)

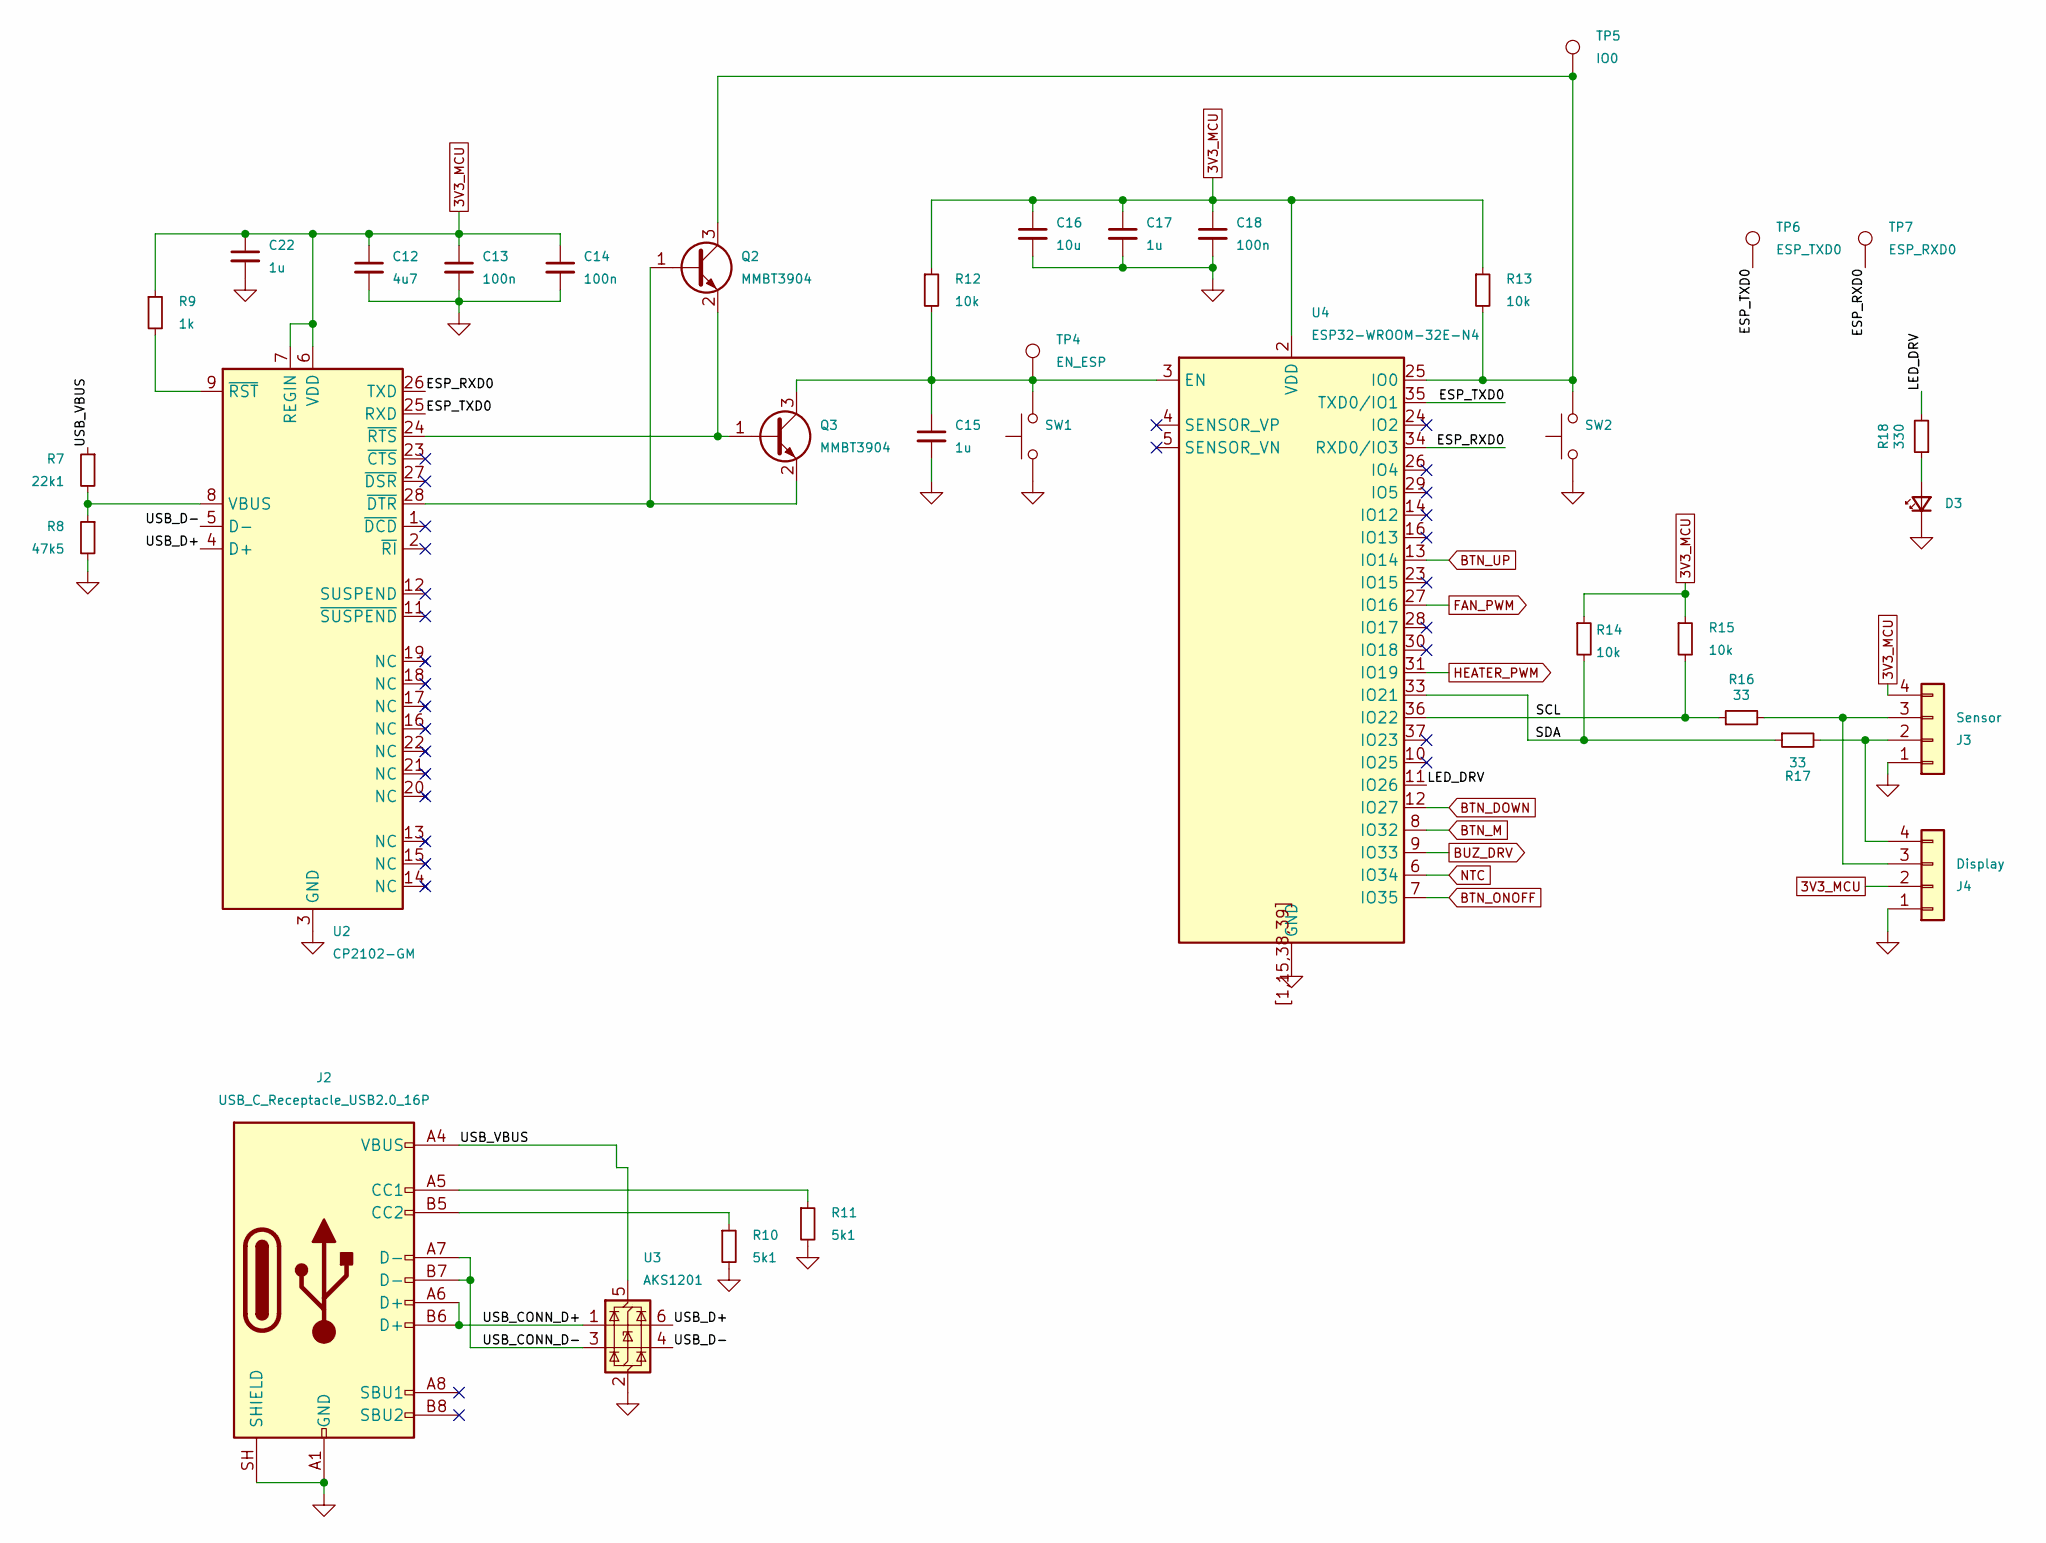
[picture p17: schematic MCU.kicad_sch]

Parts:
C12: 4u7; C_0603_1608Metric; Tolerance 10%; Voltage 16V; MPN CL10A475KO8NNNC
C13, C14, C18: 100n; C_0603_1608Metric; Tolerance 10%; Voltage 50V; MPN CC0603KRX7R9BB104
C15, C17, C22: 1u; C_0603_1608Metric; Tolerance 10%; Voltage 25V; MPN GCM188R71E105KA64J
C16: 10u; C_0805_2012Metric; Tolerance 10%; Voltage 25V; MPN C0805C106K3PACTU
D3: LED_Small; LED_0805_2012Metric; MPN HSMG-C170
J2: USB_C_Receptacle_USB2.0_16P; USB_C_GCT_USB4216-03-A; MPN USB4216-03-A
J3: Sensor; JST_PH_B4B-PH-SM4-TB_1x04-1MP_P2.00mm_Vertical; MPN B4B-PH-SM4-TB (LF)(SN)
J4: Display; Oled 1.54 Inch SSD1309 TZT
Q2, Q3: MMBT3904; SOT-23; MPN MMBT3904
R7: 22k1; R_0603_1608Metric; Tolerance 1%; Voltage 75V; MPN RC0603FR-1322K1L
R8: 47k5; R_0603_1608Metric; Tolerance 1%; Voltage 75V; MPN RC0603FR-0747K5L
R9: 1k; R_0603_1608Metric; Tolerance 1%; Voltage 75V; MPN RC0603FR-071KL
R10, R11: 5k1; R_0603_1608Metric; Tolerance 1%; Voltage 75V; MPN RC0603FR-075K1L
R12, R13, R14, R15: 10k; R_0603_1608Metric; Tolerance 1%; Voltage 75V; MPN RC0603FR-0710KL
R16, R17: 33; R_0603_1608Metric; Tolerance 1%; Voltage 75V; MPN RC0603FR-0733RL
R18: 330; R_0603_1608Metric; Tolerance 1%; Voltage 75V; MPN RC0603FR-07330RL
SW1, SW2: SW_GCT_SWT0110; MPN SWT0110-020010SSA
TP4: EN_ESP; TestPoint_Pad_1.5x1.5mm
TP5: IO0; TestPoint_Pad_1.5x1.5mm
TP6: ESP_TXD0; TestPoint_Pad_1.5x1.5mm
TP7: ESP_RXD0; TestPoint_Pad_1.5x1.5mm
U2: CP2102-GM; CP2102_GM_QFN28_5x5_P0.5_EP3.25; MPN CP2102-GM
U3: AKS1201; SOT-23-6; MPN AKS1201
U4: ESP32-WROOM-32E-N4; ESP32-WROOM-32E; MPN ESP32-WROOM-32E-N4

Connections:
3V3_MCU: C12.1, C13.1, C14.1, C16.1, C17.1, C18.1, C22.1, J3.4, J4.2, R9.1, R12.1, R13.1, R14.1, R15.1, U2.6 (VDD), U2.7 (REGIN), U4.2 (VDD); also elsewhere on the board
/MCU/ESP_RXD0: TP7.1 (1_1), U2.26 (TXD), U4.34 (RXD0/IO3)
/MCU/ESP_TXD0: TP6.1 (1_1), U2.25 (RXD), U4.35 (TXD0/IO1)
/MCU/LED_DRV: R18.2, U4.11 (IO26)
/MCU/SCL: R15.2, R16.1, U4.36 (IO22)
/MCU/SDA: R14.2, R17.1, U4.33 (IO21)
/MCU/USB_CONN_D+: J2.A6 (D+), J2.B6 (D+), U3.1 (I/O1)
/MCU/USB_CONN_D-: J2.A7 (D-), J2.B7 (D-), U3.3 (I/O2)
/MCU/USB_D+: U2.4 (D+), U3.6 (I/O1)
/MCU/USB_D-: U2.5 (D-), U3.4 (I/O2)
/MCU/USB_VBUS: J2.A4 (VBUS), J2.A9 (VBUS), J2.B4 (VBUS), J2.B9 (VBUS), R7.1, U3.5 (VBUS)
BTN_DOWN: U4.12 (IO27); also elsewhere on the board
BTN_M: U4.8 (IO32); also elsewhere on the board
BTN_ONOFF: U4.7 (IO35); also elsewhere on the board
BTN_UP: U4.13 (IO14); also elsewhere on the board
BUZ_DRV: U4.9 (IO33); also elsewhere on the board
FAN_PWM: U4.27 (IO16); also elsewhere on the board
GND: C12.2, C13.2, C14.2, C15.2, C16.2, C17.2, C18.2, C22.2, D3.1 (K), J2.A1 (GND), J2.A12 (GND), J2.B1 (GND), J2.B12 (GND), J2.SH (SHIELD), J3.1, J4.1, R8.2, R10.2, R11.2, SW1.1, SW2.1, U2.3 (GND), U2.29 (GND), U3.2 (GND), U4.1 (GND), U4.15 (GND), U4.38 (GND), U4.39 (GND), U4.[1,15,38,39] (GND); also elsewhere on the board
HEATER_PWM: U4.31 (IO19); also elsewhere on the board
NTC: U4.6 (IO34); also elsewhere on the board
unnamed: D3.2 (A), R18.1
unnamed: J2.A5 (CC1), R11.1
unnamed: J2.B5 (CC2), R10.1
unnamed: J3.2, J4.4, R17.2
unnamed: J3.3, J4.3, R16.2
unnamed: Q2.1 (B), Q3.2 (E), U2.28 (~DTR)
unnamed: Q2.3 (C), R13.2, SW2.2, TP5.1 (1_1), U4.25 (IO0)
unnamed: Q2.2 (E), Q3.1 (B), U2.24 (~RTS)
unnamed: C15.1, Q3.3 (C), R12.2, SW1.2, TP4.1 (1_1), U4.3 (EN)
unnamed: R7.2, R8.1, U2.8 (VBUS)
unnamed: R9.2, U2.9 (~RST)

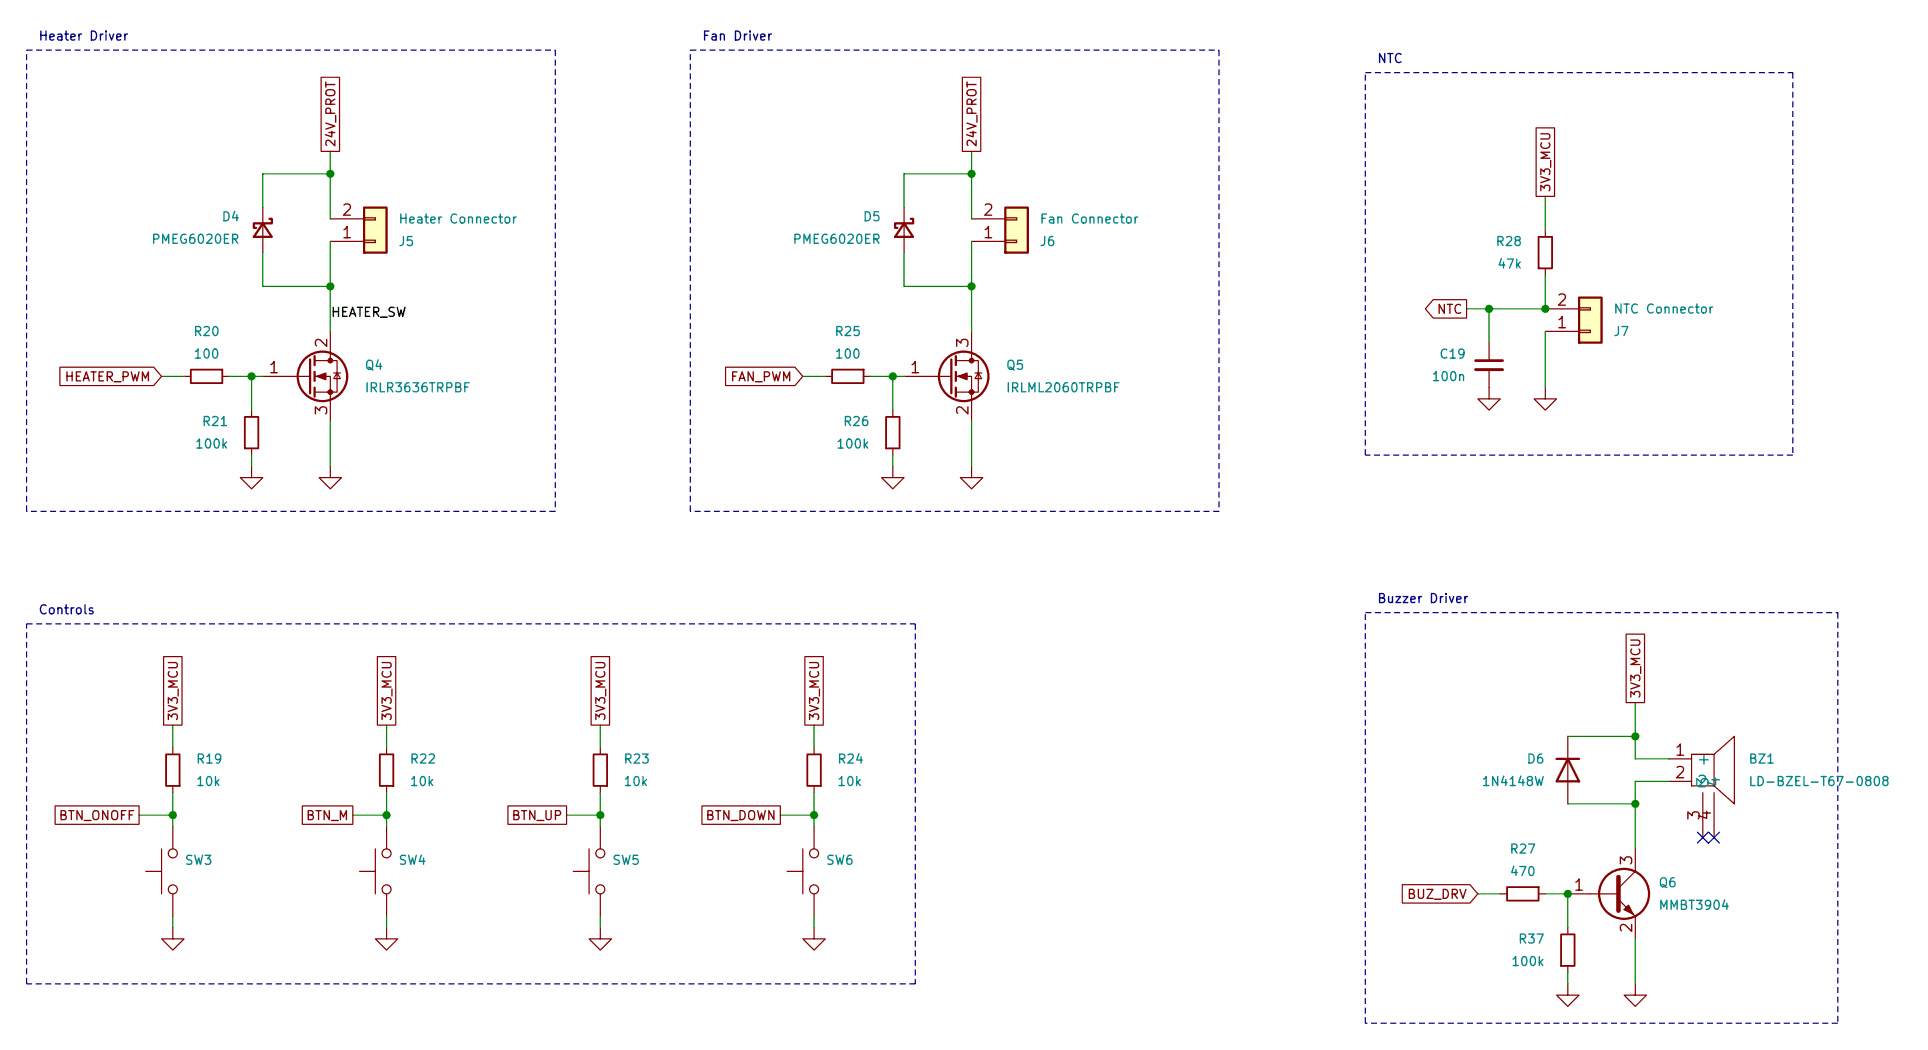
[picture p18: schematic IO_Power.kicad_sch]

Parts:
BZ1: LD-BZEL-T67-0808; BUZ_Loudity_SMT67_8.5x8.5; MPN LD-BZEL-T67-0808
C19: 100n; C_0603_1608Metric; Tolerance 10%; Voltage 50V; MPN CC0603KRX7R9BB104
D4, D5: PMEG6020ER; Nexperia_CFP3_SOD-123W; MPN PMEG6020ER,115
D6: 1N4148W; D_SOD-123; MPN 1N4148WGW
J5: Heater Connector; JST_XH_B2B-XH-A_1x02_P2.50mm_Vertical; MPN Kit HALJIA XH-compatible 2P
J6: Fan Connector; JST_PH_B2B-PH-SM4-TB_1x02-1MP_P2.00mm_Vertical; MPN B2B-PH-SM4-TB (LF)(SN)
J7: NTC Connector; JST_GH_BM02B-GHS-TBT_1x02-1MP_P1.25mm_Vertical; MPN BM02B-GHS-TBT (LF)(SN)(N)
Q4: IRLR3636TRPBF; TO-252-2; MPN IRLR3636TRPBF
Q5: IRLML2060TRPBF; SOT-23; MPN IRLML2060TRPBF
Q6: MMBT3904; SOT-23; MPN MMBT3904
R19, R22, R23, R24: 10k; R_0603_1608Metric; Tolerance 1%; Voltage 75V; MPN RC0603FR-0710KL
R20, R25: 100; R_0603_1608Metric; Tolerance 1%; Voltage 75V; MPN RC0603FR-07100RL
R21, R26, R37: 100k; R_0603_1608Metric; Tolerance 1%; Voltage 75V; MPN RC0603FR-07100KL
R27: 470; R_0603_1608Metric; Tolerance 1%; Voltage 75V; MPN RC0603FR-07470RL
R28: 47k; R_0603_1608Metric; Tolerance 1%; Voltage 75V; MPN RC0603FR-0747KL
SW3, SW4, SW5, SW6: SW_GCT_SWT0110; MPN SWT0110-020010SSA

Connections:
3V3_MCU: BZ1.1 (+), D6.1 (K), R19.2, R22.2, R23.2, R24.2, R28.2; also elsewhere on the board
24V_PROT: D4.1 (K), D5.1 (K), J5.2, J6.2; also elsewhere on the board
/IO_Power/HEATER_SW: D4.2 (A), J5.1, Q4.2 (D)
BTN_DOWN: R24.1, SW6.2; also elsewhere on the board
BTN_M: R22.1, SW4.2; also elsewhere on the board
BTN_ONOFF: R19.1, SW3.2; also elsewhere on the board
BTN_UP: R23.1, SW5.2; also elsewhere on the board
BUZ_DRV: R27.2; also elsewhere on the board
FAN_PWM: R25.2; also elsewhere on the board
GND: C19.2, J7.1, Q4.3 (S), Q5.2 (S), Q6.2 (E), R21.1, R26.1, R37.1, SW3.1, SW4.1, SW5.1, SW6.1; also elsewhere on the board
HEATER_PWM: R20.2; also elsewhere on the board
NTC: C19.1, J7.2, R28.1; also elsewhere on the board
unnamed: D5.2 (A), J6.1, Q5.3 (D)
unnamed: BZ1.2, D6.2 (A), Q6.3 (C)
unnamed: Q4.1 (G), R20.1, R21.2
unnamed: Q5.1 (G), R25.1, R26.2
unnamed: Q6.1 (B), R27.1, R37.2

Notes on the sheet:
Buzzer Driver
Controls
Fan Driver
Heater Driver
NTC

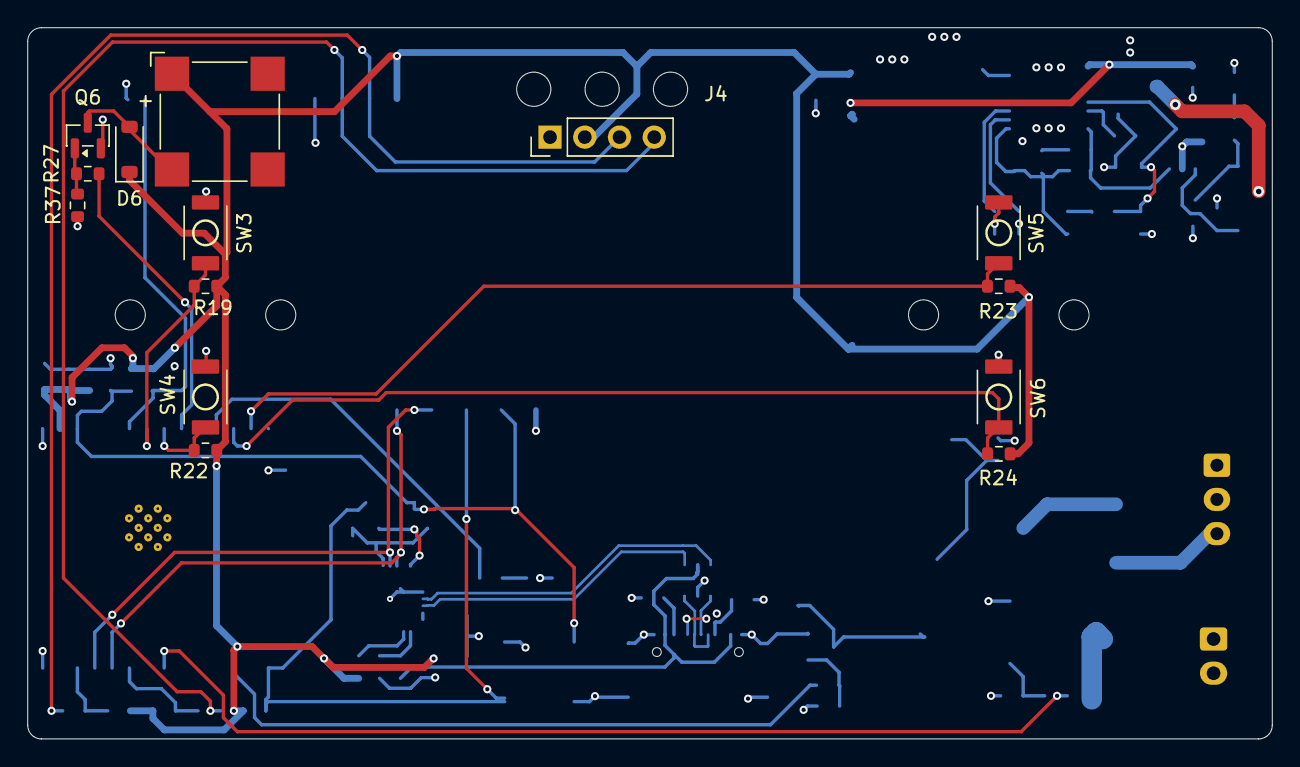
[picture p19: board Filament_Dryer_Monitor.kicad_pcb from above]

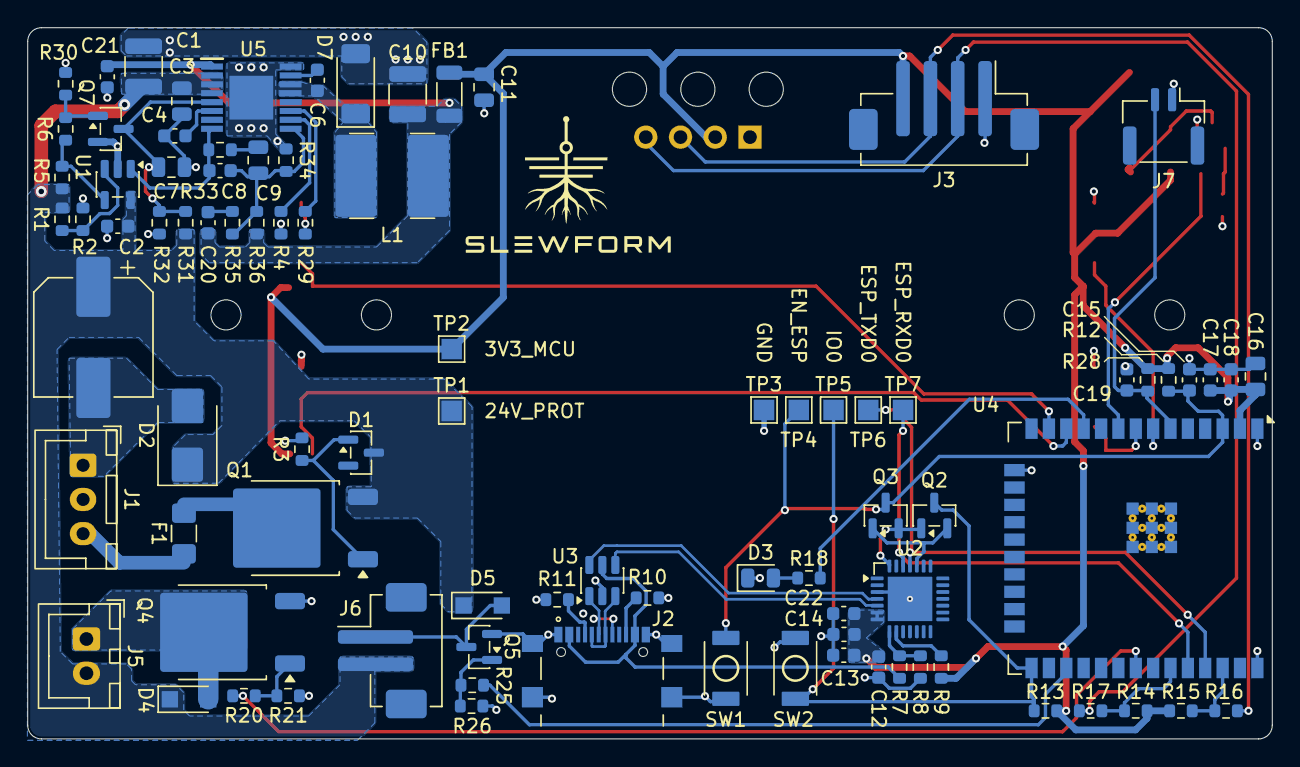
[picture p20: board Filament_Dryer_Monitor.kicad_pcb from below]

Board: 4 copper layers, 91.0 x 52.0 mm, 102 parts (88 on the bottom side), 55 nets.

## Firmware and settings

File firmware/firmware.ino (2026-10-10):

#include <Arduino.h>
#include <Wire.h>
#include <U8g2lib.h>

#include "AppConfig.h"
#include "AppTypes.h"
#include "ButtonManager.h"
#include "Buzzer.h"
#include "CycleController.h"
#include "FanController.h"
#include "SafetyController.h"
#include "SettingsStore.h"
#include "Sht45Sensor.h"
#include "StatusLed.h"
#include "Ui.h"

U8G2_SSD1309_128X64_NONAME0_F_HW_I2C oled(U8G2_R0, U8X8_PIN_NONE);

ButtonManager buttons;
Buzzer buzzer;
CycleController cycle;
FanController fan;
SafetyController safety;
SettingsStore settingsStore;
Sht45Sensor sht45(Wire);
StatusLed statusLed;
Ui ui(oled);

AppState appState = AppState::Boot;
SetupField setupField = SetupField::Temperature;
SettingsField settingsField = SettingsField::BuzzerVolume;
PersistentSettings settings;

uint32_t bootStartedMs = 0;
bool bootWordmarkChimeStarted = false;
bool technicalPage = false;

static void applyBuzzerSettings() {
  buzzer.setVolume(settings.buzzerVolume);
}

static void enterState(AppState next, uint32_t nowMs) {
  if (appState == AppState::Drying && next != AppState::Drying) {
    cycle.stop();
    fan.stop();
  }

  appState = next;
  technicalPage = false;
  ui.noteInteraction(nowMs);

  switch (next) {
    case AppState::Standby:
      fan.stop();
      Serial.println("STATE -> STANDBY");
      break;
    case AppState::Setup:
      fan.stop();
      Serial.println("STATE -> SETUP");
      break;
    case AppState::Settings:
      fan.stop();
      settingsField = SettingsField::BuzzerVolume;
      Serial.println("STATE -> SETTINGS");
      break;
    case AppState::Drying:
      settingsStore.save(settings);
      cycle.start(settings.cycle, nowMs);
      fan.startAuto(nowMs);
      buzzer.playCycleStart(nowMs);
      Serial.println("STATE -> DRYING TEST (fan active; heater locked OFF)");
      break;
    case AppState::Complete:
      fan.stop();
      buzzer.playComplete(nowMs);
      Serial.println("STATE -> COMPLETE");
      break;
    case AppState::Fault:
      fan.stop();
      buzzer.startFaultAlarm(nowMs);
      Serial.println("STATE -> FAULT");
      break;
    case AppState::Boot:
      fan.stop();
      break;
  }
}

static void selectNextSetupField() {
  switch (setupField) {
    case SetupField::Temperature: setupField = SetupField::Duration; break;
    case SetupField::Duration: setupField = SetupField::Fan; break;
    case SetupField::Fan: setupField = SetupField::Temperature; break;
  }
}

static void selectNextSettingsField() {
  settingsField = (settingsField == SettingsField::BuzzerVolume)
                      ? SettingsField::KeyClick
                      : SettingsField::BuzzerVolume;
}

static void adjustSetup(int8_t direction) {
  if (setupField == SetupField::Temperature) {
    const int16_t next =
        settings.cycle.targetTempC +
        direction * AppConfig::kPrototypeTempStepC;
    settings.cycle.targetTempC =
        constrain(next, AppConfig::kPrototypeTempMinC,
                  AppConfig::kPrototypeTempMaxC);
  } else if (setupField == SetupField::Duration) {
    const int32_t next =
        static_cast<int32_t>(settings.cycle.durationMinutes) +
        direction *
            static_cast<int32_t>(AppConfig::kPrototypeDurationStepMinutes);
    settings.cycle.durationMinutes = static_cast<uint16_t>(constrain(
        next,
        static_cast<int32_t>(AppConfig::kPrototypeDurationMinMinutes),
        static_cast<int32_t>(AppConfig::kPrototypeDurationMaxMinutes)));
  }
}

static void adjustSettings(int8_t direction, uint32_t nowMs) {
  if (settingsField == SettingsField::BuzzerVolume) {
    int value = static_cast<int>(settings.buzzerVolume) + direction;
    value = constrain(value, static_cast<int>(BuzzerVolume::Off),
                      static_cast<int>(BuzzerVolume::High));
    settings.buzzerVolume = static_cast<BuzzerVolume>(value);
    applyBuzzerSettings();
    buzzer.playVolumePreview(nowMs);
  } else {
    settings.keyClick = !settings.keyClick;
    if (settings.keyClick) buzzer.playKeyClick(nowMs);
  }
}

static void maybePlayKeyClick(ButtonEventType type, uint32_t nowMs) {
  if (!settings.keyClick || type == ButtonEventType::Repeat) return;
  buzzer.playKeyClick(nowMs);
}

static void handleButtonEvent(ButtonId id, ButtonEventType type) {
  const uint32_t nowMs = millis();

  if (ui.wakeAndConsumeIfSleeping(nowMs)) {
    Serial.println("OLED wake: button event consumed");
    return;
  }
  ui.noteInteraction(nowMs);

  if (appState != AppState::Fault) {
    maybePlayKeyClick(type, nowMs);
  }

  switch (appState) {
    case AppState::Boot:
      return;

    case AppState::Standby:
      if (id == ButtonId::Mode && type == ButtonEventType::ShortPress) {
        setupField = SetupField::Temperature;
        enterState(AppState::Setup, nowMs);
      } else if (id == ButtonId::Mode &&
                 type == ButtonEventType::LongPress) {
        enterState(AppState::Settings, nowMs);
      } else if (id == ButtonId::OnOff &&
                 type == ButtonEventType::ShortPress) {
        enterState(AppState::Drying, nowMs);
      }
      return;

    case AppState::Setup:
      if (id == ButtonId::Mode && type == ButtonEventType::ShortPress) {
        selectNextSetupField();
      } else if (id == ButtonId::Mode &&
                 type == ButtonEventType::LongPress) {
        settingsStore.save(settings);
        enterState(AppState::Standby, nowMs);
      } else if (id == ButtonId::OnOff &&
                 type == ButtonEventType::ShortPress) {
        enterState(AppState::Drying, nowMs);
      } else if ((id == ButtonId::Up || id == ButtonId::Down) &&
                 (type == ButtonEventType::ShortPress ||
                  type == ButtonEventType::Repeat)) {
        adjustSetup(id == ButtonId::Up ? +1 : -1);
      }
      return;

    case AppState::Settings:
      if (id == ButtonId::Mode && type == ButtonEventType::ShortPress) {
        selectNextSettingsField();
      } else if (id == ButtonId::Mode &&
                 type == ButtonEventType::LongPress) {
        settingsStore.save(settings);
        enterState(AppState::Standby, nowMs);
      } else if ((id == ButtonId::Up || id == ButtonId::Down) &&
                 (type == ButtonEventType::ShortPress ||
                  type == ButtonEventType::Repeat)) {
        adjustSettings(id == ButtonId::Up ? +1 : -1, nowMs);
      }
      return;

    case AppState::Drying:
      if (id == ButtonId::Mode && type == ButtonEventType::ShortPress) {
        technicalPage = !technicalPage;
      } else if (id == ButtonId::OnOff &&
                 type == ButtonEventType::LongPress) {
        enterState(AppState::Standby, nowMs);
      }
      return;

    case AppState::Complete:
      if (id == ButtonId::OnOff &&
          type == ButtonEventType::ShortPress) {
        enterState(AppState::Standby, nowMs);
      }
      return;

    case AppState::Fault:
      if (id == ButtonId::Mode &&
          type == ButtonEventType::ShortPress) {
        buzzer.muteFault();
        Serial.println("Fault buzzer muted; fault remains active");
      }
      return;
  }
}

void setup() {
  safety.begin();
  statusLed.begin();
  buttons.begin();
  fan.begin();

  Wire.begin(AppConfig::kPinSda, AppConfig::kPinScl,
             AppConfig::kI2cFrequencyHz);
  const uint32_t nowMs = millis();
  ui.begin(nowMs);

  Serial.begin(115200);
  Serial.println();
  Serial.println("Filament Dryer Monitor - SAFE BRING-UP application");
  Serial.println("Heater locked OFF. Fan test control enabled.");

  const bool settingsOk = settingsStore.begin(settings);
  if (!settingsOk) {
    Serial.println("WARNING: Preferences/NVS unavailable; using defaults");
  }

  sht45.begin(nowMs);
  buzzer.begin();
  applyBuzzerSettings();

  bootStartedMs = nowMs;
  appState = AppState::Boot;
  bootWordmarkChimeStarted = false;  // Roots grow in silence.

  if (!fan.attached()) {
    Serial.println("WARNING: fan LEDC attachment failed; fan remains OFF");
  }

  ui.render(nowMs, appState, setupField, settingsField, settings,
            sht45.snapshot(), 0, fan.dutyPercent(), false,
            nowMs - bootStartedMs);
}

void loop() {
  const uint32_t nowMs = millis();

  safety.update();

  buttons.update(nowMs, handleButtonEvent);
  buzzer.update(nowMs);
  sht45.update(nowMs);
  fan.update(nowMs, safety.fanPermitted());

  if (appState == AppState::Boot) {
    const uint32_t elapsedMs = nowMs - bootStartedMs;
    if (elapsedMs >= AppConfig::kBootSplashMs) {
      enterState(AppState::Standby, nowMs);
    } else if (!bootWordmarkChimeStarted &&
               elapsedMs >= AppConfig::kBootWordmarkStartMs) {
      bootWordmarkChimeStarted = true;
      ui.requestRender(nowMs);  // Make the wordmark appear in this loop pass.
      buzzer.playStartup(nowMs);
    }
  }

  if (cycle.update(nowMs) == CycleEvent::Completed) {
    enterState(AppState::Complete, nowMs);
  }

  if (safety.faultActive() && appState != AppState::Fault) {
    enterState(AppState::Fault, nowMs);
  }

  const bool sensorHealthy = sht45.healthy(nowMs);
  DiagnosticLedState ledState = DiagnosticLedState::Boot;
  if (appState == AppState::Fault) {
    ledState = DiagnosticLedState::Fault;
  } else if (appState == AppState::Boot) {
    ledState = DiagnosticLedState::Boot;
  } else if (!sensorHealthy) {
    ledState = DiagnosticLedState::Warning;
  } else {
    ledState = DiagnosticLedState::Normal;
  }
  statusLed.update(nowMs, ledState);

  ui.updateSleep(nowMs, appState);
  ui.render(nowMs, appState, setupField, settingsField, settings,
            sht45.snapshot(), cycle.remainingSeconds(nowMs),
            fan.dutyPercent(), technicalPage, nowMs - bootStartedMs);
}

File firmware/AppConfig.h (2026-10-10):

#pragma once
#include <Arduino.h>

namespace AppConfig {

constexpr uint8_t kPinSda = 21;
constexpr uint8_t kPinScl = 22;
constexpr uint8_t kPinStatusLed = 26;
constexpr uint8_t kPinFanPwm = 16;
constexpr uint8_t kPinBuzzer = 33;
constexpr uint8_t kPinHeaterPwm = 19;
constexpr uint8_t kPinNtcAdc = 34;
constexpr uint8_t kPinButtonOnOff = 35;
constexpr uint8_t kPinButtonMode = 32;
constexpr uint8_t kPinButtonUp = 14;
constexpr uint8_t kPinButtonDown = 27;

constexpr uint8_t kOledAddress = 0x3C;
constexpr uint8_t kSht45Address = 0x44;
constexpr uint32_t kI2cFrequencyHz = 100000;

constexpr uint32_t kBootSplashMs = 3500;
// First show the growing roots silently; start chime on the solo wordmark.
constexpr uint32_t kBootWordmarkStartMs = 2100;
constexpr uint32_t kDisplaySleepMs = 60000;
constexpr uint32_t kRenderPeriodMs = 100;
constexpr uint32_t kButtonDebounceMs = 30;
constexpr uint32_t kButtonLongPressMs = 1500;
constexpr uint32_t kButtonRepeatDelayMs = 500;
constexpr uint32_t kButtonRepeatPeriodMs = 120;
constexpr uint32_t kSht45PeriodMs = 2000;
constexpr uint32_t kSht45ConversionMs = 12;
constexpr uint32_t kSht45StaleMs = 10000;

// SAFE BRING-UP: heater remains hard-disabled.
// These UI bounds are provisional and are NOT heater safety limits.
constexpr int16_t kPrototypeTempMinC = 30;
constexpr int16_t kPrototypeTempMaxC = 80;
constexpr int16_t kPrototypeTempStepC = 1;
constexpr uint16_t kPrototypeDurationMinMinutes = 15;
constexpr uint16_t kPrototypeDurationMaxMinutes = 12 * 60;
constexpr uint16_t kPrototypeDurationStepMinutes = 15;

// Fan first-article bring-up policy.
// Measured at 25 kHz: 25% first tested start duty, 15% sustained-running floor.
constexpr uint32_t kFanPwmFrequencyHz = 25000;
constexpr uint8_t kFanPwmResolutionBits = 8;
constexpr uint8_t kFanLedcChannel = 9;
constexpr uint32_t kFanKickstartMs = 1000;
constexpr uint8_t kFanKickstartPercent = 100;
constexpr uint8_t kFanBringupRunPercent = 40;

constexpr uint8_t kBuzzerResolutionBits = 8;
constexpr uint8_t kBuzzerLedcChannel = 8;
constexpr uint8_t kBuzzerDutyLow = 12;
constexpr uint8_t kBuzzerDutyMedium = 24;
constexpr uint8_t kBuzzerDutyHigh = 48;

constexpr uint16_t kSettingsSchemaVersion = 1;

}  // namespace AppConfig

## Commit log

2026-07-20 Initial commit: schematic complete, PCB layout in progress
    [B2B-PH-SM4-TB.STEP, B4B-PH-SM4-TB.STEP, Filament_Dryer_Monitor.kicad_pcb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]
2026-07-26 PCB layout progress before board resize
    [Filament_Dryer_Monitor.kicad_pcb]
2026-07-28 Board resize in progress
    [Filament_Dryer_Monitor.csv, Filament_Dryer_Monitor.kicad_pcb, Filament_Dryer_Monitor_comp_reference_function.csv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]
2026-07-31 Update README: GPIO map (fan/up/down pins), button description, board size under revision
    [Filament_Dryer_Monitor.kicad_pcb, MCU.kicad_sch]
2026-08-04 Add MPN/LCSC/Manufacturer fields to components; layout WIP
    Claude-Session: https://claude.ai/code/session_01TtYFysfg3KHuTv6C83JsmH
    [Filament_Dryer_Monitor.kicad_pcb, IO_Power.kicad_sch, MCU.kicad_sch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]
2026-08-05 Add MPN/LCSC/Manufacturer fields to components; layout WIP
    Claude-Session: https://claude.ai/code/session_019K6fhgSgEV4SPy8guMLbu9
    [Filament_Dryer_Monitor.kicad_pcb, IO_Power.kicad_sch, MCU.kicad_sch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]
2026-08-06 Complete PCB layout: first release-ready hardware revision
    Finalize board layout, add J3 sensor connector to BOM/position files,
    and fix switch label properties (Value/Function swapped for SW1-6).
    [Filament_Dryer_Monitor.kicad_pcb, IO_Power.kicad_sch, MCU.kicad_sch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]
2026-08-06 Track DRC/ERC reports and netlist; stop ignoring generated KiCad outputs
    Claude-Session: https://claude.ai/code/session_01ADLcUMjk7wi9Tsy2Vp7nao
2026-08-07 Add HEATER_SW net label and tighten via design rules
    Rename Power_Heat netclass pattern to match the new HEATER_SW label,
    reduce min via annular width/diameter, and update PCB layout
    accordingly. Add STL export of the board.
    [Filament_Dryer_Monitor.kicad_pcb, Filament_dryer_pcb.stl, IO_Power.kicad_sch]
2026-08-09 Optimize heater MOSFET and NTC input
    [Filament_Dryer_Monitor.kicad_pcb, Filament_Dryer_Monitor.kicad_sch, IO_Power.kicad_sch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]
2026-08-09 Finalize schematic and PCB revision
    [Filament_Dryer_Monitor.kicad_pcb, IO_Power.kicad_sch, MCU.kicad_sch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]
2026-08-18 Freeze original PCB before Mouser footprint variant
    [Filament_Dryer_Monitor.kicad_pcb, Power.kicad_sch]
2026-08-30 Document L7987L buck redesign
2026-08-31 Add L7987L buck redesign schematic with AutoEN protection
    [Filament_Dryer_Monitor.kicad_sch, IO_Power.kicad_sch, MCU.kicad_sch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]
2026-08-31 Document L7987L buck redesign checkpoint
2026-08-31 Corrected pins in TLV1701 symbol and added bypass cap on its V+
    [buck_redesign_sch.kicad_sch]
2026-08-31 Added components to comparator block
    [buck_redesign_sch.kicad_sch]
2026-08-31 Updated power schematic, delated buck schematic
    [Filament_Dryer_Monitor.kicad_sch, Power.kicad_sch, buck_redesign_sch.kicad_sch]
2026-09-01 Updated buck circuit references
    [Power.kicad_sch]
2026-09-01 Update procurement docs for integrated buck redesign
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2026-09-01 Add buzzer transistor base pull-down
    [IO_Power.kicad_sch, Power.kicad_sch, buck_redesign_sch.kicad_sch]
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2026-09-02 Sync KiCad component metadata with TME BOM
    [IO_Power.kicad_sch, MCU.kicad_sch, Power.kicad_sch]
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2026-09-02 Updated R344 and R36 values
    [IO_Power.kicad_sch, MCU.kicad_sch, Power.kicad_sch]
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2026-09-02 Assign verified footprints for sourced components
    [MCU.kicad_sch, Power.kicad_sch]
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2026-09-02 Close sourced component footprint audit
    [IO_Power.kicad_sch, MCU.kicad_sch]
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2026-09-02 Fix strict symbol and pinout mappings
    [IO_Power.kicad_sch, MCU.kicad_sch, Power.kicad_sch]
2026-09-02 Finalize strict component pinout audit
    [MCU.kicad_sch, Power.kicad_sch]
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2026-09-02 Fix BZX84 KiCad symbol unit names
    [Power.kicad_sch]
2026-09-04 footprint updates
    [EEEFK1H101P.stp, SRN6045-150M.stp, USB4216-03-A.stp]
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2026-09-06 Sync PCB with L7987L schematic
    [Filament_Dryer_Monitor.kicad_pcb]
2026-09-06 first buck converter placement
    [Filament_Dryer_Monitor.kicad_pcb]
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2026-09-06 Place power components on bottom
    [Filament_Dryer_Monitor.kicad_pcb]
2026-09-07 Uopdated buck layout
    [Filament_Dryer_Monitor.kicad_pcb]
2026-09-07 updated layout
    [Filament_Dryer_Monitor.kicad_pcb]
2026-09-07 Layout update
    [Filament_Dryer_Monitor.kicad_pcb]
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2026-09-09 Added C22 1uF
    [Filament_Dryer_Monitor.kicad_pcb, IO_Power.kicad_sch, MCU.kicad_sch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]
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2026-09-09 updated vias on U5 and D7
    [Filament_Dryer_Monitor.kicad_pcb, Power.kicad_sch]
2026-09-09 updated D7 footprint
    [Filament_Dryer_Monitor.kicad_pcb]
2026-09-11 Removed C22
    [Filament_Dryer_Monitor.kicad_pcb, Power.kicad_sch]
2026-09-11 updated pcb
    [Filament_Dryer_Monitor.kicad_pcb]
2026-09-11 added vias to power gnd
    [Filament_Dryer_Monitor.kicad_pcb]
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2026-09-17 updated footprints
    [Filament_Dryer_Monitor.kicad_pcb]
2026-09-17 Updated schematic and erc
    [Filament_Dryer_Monitor.kicad_pcb, MCU.kicad_sch]
2026-09-17 Production files
    [Filament_Dryer_Monitor.kicad_pcb, Filament_Dryer_Monitor_bom.csv, Filament_Dryer_Monitor_designators.csv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]
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2026-09-21 docs: replace stale release TODO with order and first-board checklist
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2026-09-21 docs: bring buck design record up to released hardware and supply state
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2026-10-01 Correct first-article functional stage grouping
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2026-10-02 Fix staged population coverage counts
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2026-10-04 Record loose U3 D-minus solder joint
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2026-10-04 Record failed automatic ESP32 upload
2026-10-04 Narrow ESP32 upload failure to stub stage
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2026-10-15 Record stabilized Sanwa versus heater NTC checkpoints and next 50 C gate
2026-10-15 Gate heater range on donor model and installed 105 C TCO compatibility
2026-10-15 Document 47 C Sanwa and NTC 28.72 kOhm stabilized heater reference
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2026-10-17 Record completed 90 C hold, seven measured points and heater duty evidence
2026-10-17 Close 90 C characterization and gate further heat tests on assembly details
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2026-10-17 Record NTC seven-point diagnostic analysis and passive viewer without altering heater control
2026-10-17 Close model comparison and track passive NTC verification rather than more heater plateaus
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2026-10-19 Track printed front panel, already-completed NTC study and immediate closed fan-only test
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2026-10-19 Update next assembled firmware acceptance with J5 connected and heat software locked
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2026-10-19 Archive historical tested firmware and documented diagnostic sketches
    * Archive validated Oct 8 integrated firmware and reconstruct documented fan bench sketches with provenance
    * Recover documented I2C, SHT45, OLED and NTC bring-up procedures as labeled reconstructions
2026-10-19 Record recovered test firmware archive and unresolved fan regression in handoff: README.md
2026-10-19 Record recovered test firmware archive and unresolved fan regression in handoff: docs/TODO.md
2026-10-19 Record recovered test firmware archive and unresolved fan regression in handoff: docs/PROJECT_STATE.md
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2026-10-23 feat: add pure fail-off heater request policy for native tests, no GPIO
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2026-10-27 docs(step08): avoid repeating STEP03; scope new data-grounded NTC/thermostat integration replay
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2026-10-27 docs(step09): correct plan—next physical test HEATER ON closed-loop SHT45, no repeat cold-device trials
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2026-10-27 docs(agents): preserve proven HEAT-capable S9A code, corrected CI and mandatory physical approval gate
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2026-10-27 docs(thermal ledger): real S9A heater ON 13-cycle trial archived; target25C missed due cumulative budget
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2026-10-28 docs(handoff): actual S9B180 completed physically; 50k NTC throttle, 25C missed, phase6 abort diagnosis required
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2026-10-29 state: replace obsolete STEP13 trial with V1 AIR40-55 user-duration controller software PASS and real heater qualification gate
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2026-10-30 TODO: one evidence-grounded supervised AIR55 heater trial protocol, measured NTC provenance and physical preflight; no short energy budget
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2026-10-30 sync accurate Oct30 AIR55 failure, measured 64/74/85 C NTC evidence, full thermostat flowchart, and host-only control status from experiment; main HEATER remains OFF
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2026-10-30 docs only: reflect current uploadable HOT-261031-N8580 experiment, archived AIR55 failure, 85/80 flowchart; main heater GPIO still OFF
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
